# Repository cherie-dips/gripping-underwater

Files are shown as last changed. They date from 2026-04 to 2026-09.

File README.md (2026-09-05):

# Grippers for Underwater Manipulation

**Dipti Dhawade** · **Sai Chinmayi Kalapatapu** · **Tanu Adhikari** · **Uday Sodhi**  

**Mentor:** Prof. Sandeep Manjanna, Plaksha University

> 🏆 **3rd Place — SP Dutt Award For Innovation and Impact**

**🌐 Project website: https://cherie-dips.github.io/gripping-underwater/**

---

Underwater manipulation remains one of the most challenging unsolved problems in marine robotics. Gripping objects underwater is fundamentally harder than in open air, water creates drag that pushes objects away as fingers approach, surfaces become slippery, and buoyancy alters effective object weight. Most industrial grippers use rigid fingers that can crush fragile specimens such as corals and sponges. The ability of a robot to physically pick up, handle, or interact with objects underwater is critical for tasks like marine biology sampling, pipeline inspection, infrastructure repair, and environmental monitoring.

Our motivation comes from our AUV project, where we found our vehicle could navigate and detect objects but had no reliable way to interact with them physically. Through our literature review, we learned that underwater grippers must serve three core functions: detachment, collection, and storage. Each demands fundamentally different gripper behaviours [1]. Rigid parallel and claw grippers dominate current designs but offer poor force control and no tactile feedback. Soft grippers address some limitations but risk tearing under cyclic pressure.

Gathering these reflections, we set out to design a general-purpose underwater gripper; one capable of reliably grasping a range of object types, including but not limited to spherical, rigid, delicate and slippery objects. Our approach uses the fin-ray effect [2], a mechanism inspired by ray-finned fish bone structure, where flexible fingers passively conform around an object upon contact, distributing load rather than concentrating it. Starting from an open-source three-finger design, we iterated to a four-finger configuration, redesigned the worm-follower actuation base, modified internal finger structures, and relocated the pivot point to increase opening range. Prototypes were 3D-printed in TPU and ABS to make them lightweight, water-resistant, and cheaper.

However, trial and error revealed a clear trade-off: moving the pivot outward improved how wide the gripper could open, but the fingertips no longer met at the centre during closure. This left a gap that stopped the gripper from grasping small or thin objects. Two fixes were explored: adding a curve to the pivot region of the finger arm, and changing the slit angles in the worm-follower base. In parallel, we investigated a rack-and-pinion mechanism where a central gear drives all fingers at once,
completely removing the dependency on pivot placement. The rack-and-pinion prototyping introduced its own problems around lateral drift of the finger and structural fragility, which were resolved through revised clamp geometry and increased wall thickness. 

---

## Prototype Iterations

| Fig 1. 3-finger fin-ray gripper | Fig 2. Iterated 4-finger design | Fig 3. Iterated 4-finger rack-and-pinion |
|:-:|:-:|:-:|
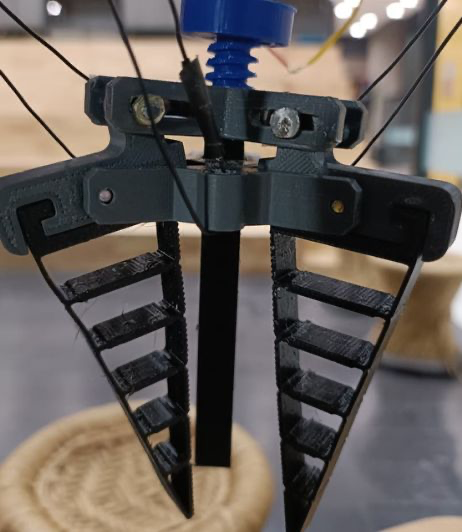
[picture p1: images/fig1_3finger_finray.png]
3-finger fin-ray gripper
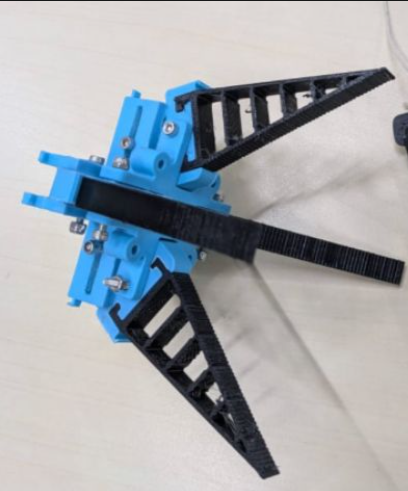
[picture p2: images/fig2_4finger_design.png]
Iterated 4-finger design
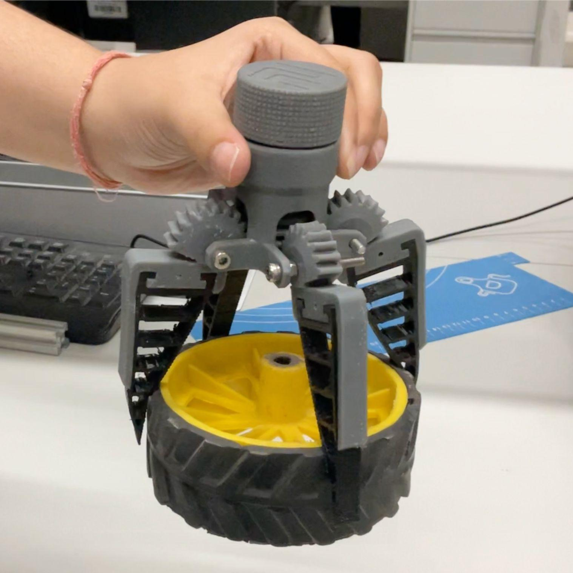
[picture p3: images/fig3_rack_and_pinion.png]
Iterated 4-finger rack-and-pinion
|  |  |  |
| *(Inspired by: "LAD Robotics")* | *(Inspired by: "Print Challenge")* | *(Inspired by: "Print Challenge")* |

---

## Next Steps

The next phase involves fabricating and comparing the fin-ray prototype against alternative mechanisms across defined test objects. Future work includes silicone moulding of finger surfaces for better grip on slippery objects and developing computer vision based grasping for robust object manipulation across different gripper types. Through our project, we aim to contribute towards expanding the current literature available on underwater grippers and the development of a more reliable, versatile, and damage-minimising gripper solution for critical marine manipulation tasks.

---

## References

[1] Mazzeo, A., Aguzzi, J., Calisti, M., Canese, S., Angiolillo, M., Allcock, A.L., Vecchi, F., Stefanni, S. and Controzzi, M., 2022. Marine robotics for deep-sea specimen collection: a taxonomy of underwater manipulative actions. *Sensors*, 22(4), p.1471.

[2] Sofla, M.S., Golshanian, H., Sklar, E.I. and Calisti, M., 2025. Modeling and modification of fin-ray effect grippers to improve their load capacity and grasp stability. *Sensors and Actuators A: Physical*, 392, p.116711.

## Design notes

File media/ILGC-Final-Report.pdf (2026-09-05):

# Autonomous Underwater Vehicle

## Grippers for Underwater Manipulation

Team Members
Dipti Dhawade (U20230146) dipti.dhawade.ug23@plaksha.edu.in Sai Chinmayi Kalapatapu (U20230085) chinmayi.k.ug23@plaksha.edu.in Tanu Adhikari (U20230115) tanu.adhikari.ug23@plaksha.ed.in Uday Sodhi (U20230020) uday.sodhi.ug23@plaksha.edu.in

Mentor: Prof. Sandeep Manjanna, Plaksha University

## Abstract

Underwater manipulation remains one of the most challenging unsolved problems in marine robotics. Existing industrial grippers are mostly rigid, which means they can crush delicate specimens like corals. Soft grippers are gentler but tend to tear under repeated pressure cycling at depth. Our AUV that we worked on earlier in ILGC could already navigate and detect objects, but had no reliable way to physically interact with them. Therefore, this project set out to design, prototype, and test a general-purpose underwater gripper capable of grasping a range of objects, including spherical, thin, slippery, and rigid ones.

We approached this by adopting the fin-ray effect, a mechanism inspired by the bone structure of ray-finned fish, where flexible fingers passively wrap around an object on contact instead of squeezing it from one direction. Starting from an open-source 3-finger design, we moved to a 4-finger configuration, redesigned the worm-follower actuation base, changed the internal structure of the finger arms, and moved the pivot point outward to increase the opening range. Parts were 3D printed in SLA, TPU and ABS.
However, trial and error revealed a clear trade-off: moving the pivot outward improved how wide the gripper could open, but the fingertips no longer met at the centre during closure. This left a gap that stopped the gripper from grasping small or thin objects. Two fixes were explored: adding a curve to the pivot region of the finger arm, and changing the slit angles in the worm-follower base. In parallel, we investigated a rack-and-pinion mechanism where a central gear drives all fingers at once, completely removing the dependency on pivot placement. The rack-and-pinion prototyping introduced its own problems around lateral drift of the finger and structural fragility, which were resolved through revised clamp geometry and increased wall thickness. The testing plan has been fully defined and will be executed before the end-semester presentation.
Future work includes silicone moulding of finger surfaces for better grip on slippery objects. This project lays the foundation for a capable, modular underwater gripper that can be handed over to the next cohort for completion and field testing.

## 1. Introduction

### 1.1 Motivation

In the previous semester of ILGC, our team worked on an Autonomous Underwater Vehicle capable of navigating underwater and identifying objects in its environment. While the vehicle could move toward and locate objects, it lacked a reliable way to physically interact with them. This gap between detection and manipulation was what motivated the gripper project. With a dependable gripper, the AUV could collect samples, retrieve objects, and perform meaningful tasks underwater rather than just observing them.

This problem turns out to be harder than it first appears. Gripping objects underwater is fundamentally different from gripping them in air. As a gripper's fingers approach an object, the surrounding water creates drag that pushes the object away before contact is even made. Once contact happens, wet surfaces are far more slippery, making it harder to maintain a secure hold. Buoyancy also changes the effective weight of the object, which affects how much force is needed to lift or move it. Together, these factors make underwater grasping significantly more challenging than the same task in air (Mazzeo et al., 2022a)

The gripper designs used in industrial underwater robotics today are mostly rigid, using parallel fingers or claw-style mechanisms. These work well for hard, robust objects but are poorly suited to anything fragile. Corals, sponges, and biological specimens can be crushed or damaged by the concentrated contact forces exerted by rigid fingers(Mazzeo et al., 2022b). Research has been moving toward softer gripper designs that wrap around an object more gently, distributing force over a larger contact area. Soft grippers are more tolerant of small positioning errors and less likely to damage delicate specimens. However, soft materials have lower mechanical strength and tend to tear under the repeated pressure changes that occur when a robot dives and resurfaces (Mazzeo et al., 2022a). Our goal was to find a design that sits between these two extremes, robust enough to function reliably but gentle enough to handle fragile objects without causing damage.

### 1.2 Problem Statement

The goal of this project was to design, prototype, and iteratively improve an underwater robotic gripper for the AUV. The gripper needed to reliably grasp a range of object types, including thin, circular, delicate, slippery, and rigid objects. It also needed to meet practical constraints: it had to be lightweight to avoid adding too much to the vehicle, water-resistant to survive the operating environment, and simple enough to be actuated by a single drive motor.

## 2. Literature Review

Given the physical challenges described above, designing an effective underwater gripper requires more than engineering intuition, it demands a systematic understanding of what such a gripper actually needs to do, what currently exists, and where existing solutions fall short. The following review builds that understanding in three steps: first, establishing what manipulation tasks and requirements define the problem space, then examining the landscape of existing gripper designs and their limitations, and finally reviewing the mechanical principles that inform a more capable approach.

### 2.1 Taxonomy of Underwater Manipulative Actions

Before evaluating any gripper design, it is necessary to understand what underwater manipulation actually involves at a task level. A foundational contribution here was made by Mazzeo et al. (2022a), who developed the first formal taxonomy of underwater manipulative actions for deep-sea specimen collection. Their methodology involved structured interviews with seventeen domain experts, marine biologists, ROV pilots, and geologists, supplemented by analysis of field video documentation. The study systematically categorised underwater manipulation into three primary task types: detachment, collection, and storage. Detachment actions ranged from non-retaining forms, such as pushing and scraping, to prehensile retaining forms, including grip-and-twist and cage-and-pull. The collection encompassed gripping, caging, suction, and tool-gripping. Storage included suction-based transfer, pouring, and object release. The taxonomy further organises these into four hierarchical levels: the full manipulation sequence, the atomic manipulation (a specific object interaction), the key-event (the period between contact creation and release), and the manipulation primitive (a basic robot command such as move or exert force). Manipulation goals are additionally classified into hand-only actions, separation actions, and release-determined actions. This decomposition is useful for mapping gripper requirements to specific task stages rather than treating manipulation as a single undifferentiated action.

Each task type maps to specific gripper contact configurations: point, edge, flat, hook, hollow, grasp, envelope, and suction flow. This framework provided a principled basis for evaluating whether any given gripper design is mechanically fit for the range of manipulation tasks encountered underwater.

The study also identified the primary failure modes of current underwater manipulators: squashing of soft specimens on full closure, poor force control dependent on pilot experience, slow closure speed that allows mobile organisms to escape, absence of force and tactile feedback, and impractical tool-change procedures in currents. These failure modes directly motivated the transition in this project from the prior cup-with-lid manipulator to a compliant, force-distributing gripper design.

Engineering requirements synthesised from this taxonomy span three dimensions:

1. Operational: grippers must be lightweight, energy-efficient, corrosion-resistant, and compatible with the arm's actuation and communication systems.
2. Environmental: they must be fully water and pressure-resistant, near-neutrally buoyant, and functional across ocean temperatures of 0°C to 3°C.
3. Task-related: requirements include high-resolution position and force control, reactive closure speed, and the capacity to handle objects ranging from sub-centimetre specimens up to 15 cm (Mazzeo et al., 2022a).

### 2.2 Existing Gripper Mechanisms and Trends

With a clear picture of what underwater grippers need to accomplish, the next question is whether existing designs meet those requirements. A companion systematic review by Mazzeo et al. (2022b) surveys the state of existing underwater grippers and organises them into four mechanical classes: parallel fingers, opposed or intermeshed fingers, grabber claws, and cage claws. Actuation is primarily hydraulic for deep-sea ROV-deployed systems, electric for laboratory and pool prototypes, and occasionally pneumatic. Associated storage systems include suction samplers, scoops, sediment corers, and Niskin bottles.

The review distinguishes prototype maturity by testing environment. Lab-tank prototypes typically combine rigid and soft technology with electric, hydraulic, or pneumatic actuation. Prototypes tested in pools or open sea conditions are predominantly purely rigid or purely soft with electric actuation. Grippers deployed on deep-sea ROVs tend toward fewer joints and actuators and are mainly hydraulically actuated. This gradient reveals a clear pattern: design complexity and softness decrease as deployment depth and operational demands increase, reflecting the current limits of soft robotic durability in high-pressure, real-world conditions.

The review identifies a consistent gap: research prototypes tend to lack robustness outside their designed scenarios, while operationally deployed marine grippers closely resemble rigid industrial designs offering limited adaptability to irregular specimen shapes. Tactile sensing remains an unsolved problem, with current workarounds relying on mechanical stiffness selection through spring-based compliance, adjusted transmission, or jamming structures, rather than direct contact feedback.

A significant documented trend is therefore a shift toward bio-inspired, soft gripper designs that address these gaps. Soft grippers offer tolerance to positioning errors and reduced risk of damage to fragile specimens. Their limitations include lower mechanical strength and susceptibility to tearing under cyclic pressurisation, a critical consideration for repeated operation. Ongoing mitigation strategies include fibre reinforcement, improved interfaces between soft and rigid components, and modular construction for simplified maintenance (Mazzeo et al., 2022b). This sets up the central design question for this project: what mechanical principles make a soft gripper both compliant and reliable?

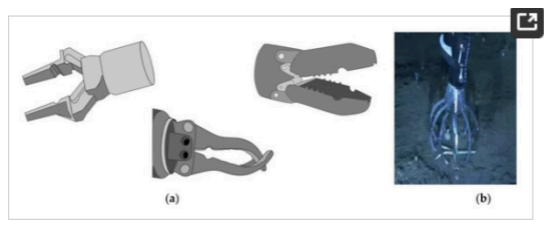
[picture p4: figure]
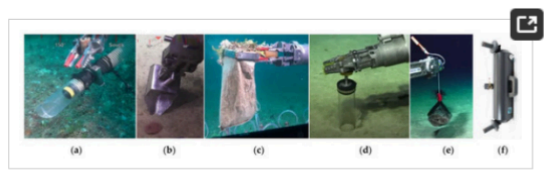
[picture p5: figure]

Fig1. Various types of Gripper and Collection tools highlighted in the paper

(Mazzeo, A., Aguzzi, J., Calisti, M., Canese, S., Vecchi, F., Stefanni, S., & Controzzi, M. (2022). Marine robotics for deep-sea specimen collection: A systematic review of underwater grippers. Sensors, 22(2), Article 648. https://doi.org/10.3390/s22020648)

### 2.3 Grasping Forces: Normal and Shear Mechanisms

Understanding why soft grippers perform better on fragile objects requires a closer look at the mechanics of grip itself. Hawkes et al. (2015) provide a useful framework, distinguishing between normal-force and shear-force grasping strategies. Normal-force approaches include wrapped or form-closure grasps, where the gripper geometrically surrounds the object and friction is not required, and squeeze or force-closure grasps, where inward clamping generates sufficient friction for a stable hold. Shear-force approaches instead exploit surface microstructure: gecko-inspired silicone ridges that activate Van der Waals adhesion forces when loaded laterally, increasing contact area without requiring compressive clamping.

This distinction is directly relevant for underwater design. The aquatic environment reduces surface friction on wet and smooth objects, making pure force-closure strategies unreliable. Form-closure, by contrast, does not depend on friction at all, making it inherently better suited to the underwater context. The fin-ray gripper pursued in this project primarily employs a form-closure strategy, where compliant fingers conform to the object's geometry and distribute load across a large contact area. The planned addition of silicone surface features draws on the Hawkes et al. (2015) finding that shear-based adhesion can supplement conformational wrapping in scenarios where geometric enclosure alone is insufficient.

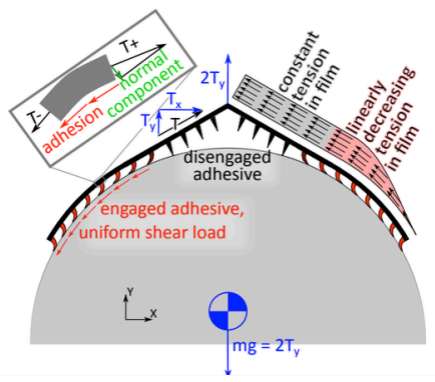
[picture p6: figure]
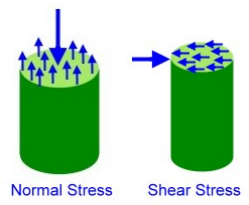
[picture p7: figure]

Fig2. Gripping using Shear Forces

(Hawkes, E.W., Christensen, D.L., Han, A.K., Jiang, H. and Cutkosky, M.R., 2015. Grasping without squeezing: Shear adhesion gripper with fibrillar thin film. In 2015 IEEE ICRA (pp. 2305-2312))

### 2.4 Fin-Ray Effect and Structural Compliance

Form-closure grasping requires fingers that can passively conform to an object's shape without active sensing or control. The Fin Ray Effect, derived from the mechanical behaviour of fish pectoral fins, provides exactly this. The geometry consists of two flexible outer beams connected by internal transverse ribs, forming a series of compliant triangular cells. When a lateral load is applied to the tip, rather than deflecting away from the force, the structure bends toward it. This counterintuitive response enables passive mechanical compliance: the finger conforms to an object's contour, increasing contact area while reducing localised pressure.

Srinivas et al. (2024) systematically investigated how different internal filling geometries affect the performance of 3D-printed fin-ray fingers, testing multiple rib and infill patterns against objects of varying shape and stiffness, including coffee cups and wooden blocks. Their key finding was that internal structure significantly influences the bending profile and grip strength of the finger, with different infill patterns suited to different object types. This provides the direct rationale for prototyping and comparing multiple internal finger geometries in this project, including the original transverse-rib design and a triangulated infill variant. The study also confirms TPU (thermoplastic polyurethane) as an appropriate finger material given its elastic memory, resistance to cyclic deformation, and printability (Srinivas et al., 2024).

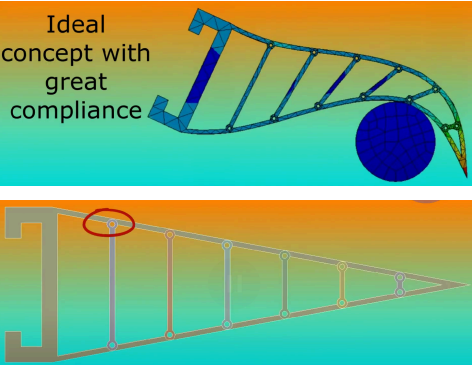
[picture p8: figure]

Fig. 3: Finray gripper deforming to envelop the object

(Image from RoboSub 2025 Technical Design Report Nanyang Technological University (NTU) )

Together, these studies form the foundation for the iterative design and prototyping approach described in the following sections.

## 3. Modelling & Analysis - Design Modifications

This section documents the full design evolution of the underwater gripper mechanism. We started with the worm-follower fin-ray gripper and then iterated it from a 3-finger to a 4-finger design. After encountering issues with the worm follower geometry, we then shifted to rack-and-pinion architecture, culminating in the decision to fabricate the final design in aluminium for structural durability.

### 3.1 Worm-Follower Fin-Ray Gripper

### 3.1.1 Design Concept and Initial Configuration

The first gripper mechanism designed for this project was based on a worm-follower actuation system combined with fin-ray fingers. In this mechanism, a motor-driven worm gear drives a follower that translates rotational motor output into the radial motion of the finger arms. All components were modelled in Fusion 360 and 3D printed in ABS and TPU. The initial printed assembly comprised a worm-follower base, a front base plate, fin-ray fingers (TPU material), and a motor-mount holder. The original design began as a 3-finger configuration, adapted from reference designs and modified in-house to suit the grasping requirements of the project.

3.1.2 3-Finger to 4-Finger Design Modification
The original 3-finger gripper (Fig. 4 (a)) was modified to a 4-finger(Fig. 4(b)) configuration as an iterative improvement. The rationale for this change was to test whether an additional finger arm would improve grasping stability, distribute grip force more evenly, and increase success rates when grasping larger, rounder, or asymmetric objects.

The following changes were made to the worm-follower base to support four fingers:

a. The base was redesigned to accommodate four equidistant arm channels instead of three.
b. The slit geometry was enlarged to allow greater freedom of movement for the rivets acting as pivot fasteners.
c. Hooks were added to the base to pull the finger arms upright after each grasping cycle, ensuring consistent return to the open position.

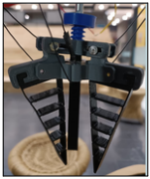
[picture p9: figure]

Fig. 4 (a) 3-finger configuration | Fig. 4 (b) 4-finger configuration

### 3.1.3 Pivot Relocation and the Closure Trade-Off

To improve the opening range of the gripper, enabling it to grasp larger and rounder objects, the pivot location of the finger arms was shifted outward(Fig. 5). This modification confirmed improved range of motion.

However, upon actuation, a significant and unexpected problem emerged: the fingers were not closing fully. Moving the pivot outward shifted the effective closing axis of each finger arm, meaning the fingertips no longer converged at the centre during closure. The result was a persistent gap at the fingertips that limited the gripper's ability to grasp small and thin objects, a direct trade-off with the improved opening range.

Two corrective approaches were evaluated to restore full closure while retaining the wider opening range:

a. Adding a curve to the pivot region of the finger arm to redirect the closing trajectory back toward the centre, compensating geometrically for the axis shift.
b. Modifying the slit angles in the worm-follower base to alter the rivet travel path and correct the closing axis without changing the finger arms themselves.
Neither approach fully resolved the trade-off. The geometric constraints of the worm-follower mechanism meant that pivot location, opening range, and closure geometry were inherently coupled and improving one parameter degraded another. This limitation made us explore an alternative actuation mechanism that could decouple these constraints entirely

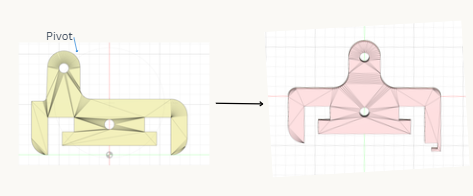
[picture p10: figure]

Fig. 5: Change in pivot point of Clamp

### 3.2 Transition to the Rack-and-Pinion Design

### 3.2.1 Rationale for the Mechanism Change

The rack-and-pinion gripper(Fig. 6) was selected as the replacement architecture after a systematic analysis of the worm-follower's structural limitations. The rack-and-pinion mechanism resolves this at the kinematic level:

- A central pinion gear, driven by the motor, meshes directly with rack teeth cut into the base of each finger.
- As the pinion rotates, all fingers are driven simultaneously and symmetrically - inward to close, outward to open.

- Both full closure and maximum opening are governed purely by rack travel length and pinion rotation, completely independent of any pivot geometry.
This architecture is also compact, straightforward to model in Fusion 360, and ensures perfect synchrony across all four fingers without additional linkage or geometry changes. We adapted an existing open-source 3-finger rack-and-pinion design (PrintChallenge) and re-engineered it for a four-finger.

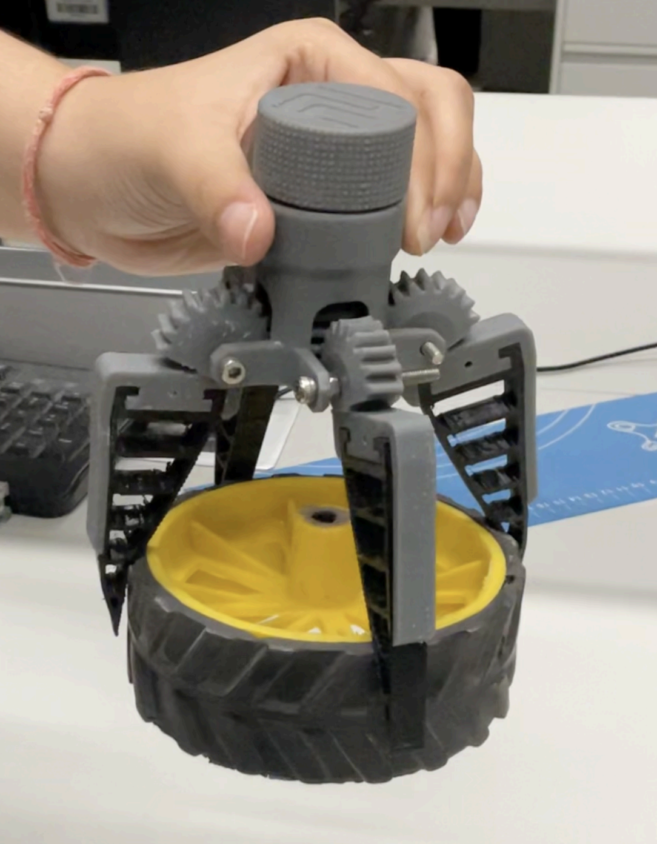
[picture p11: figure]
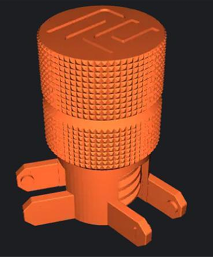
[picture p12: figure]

Fig. 6: Rack and pinion design

### 3.2.2 Rack-and-Pinion Design Iterations

Following the mechanism transition, the rack-and-pinion gripper underwent four distinct design iterations. Each iteration was driven by a specific failure observed during physical prototyping.

Iteration 1 - Initial Clamp: Lateral Drift Failure

Upon assembling and actuating the initial clamp design, the finger arms were found to deflect tangentially, sliding sideways perpendicular to their intended radial axis of motion. This lateral drift caused misalignment during closure, preventing a clean and symmetric grip.

Root cause: No lateral constraint geometry in the clamp channels; the finger arms had freedom to move tangentially as well as radially.

Corrective action: The clamp was redesigned to incorporate lateral guide walls that confine each finger arm strictly to its radial axis, eliminating tangential drift.

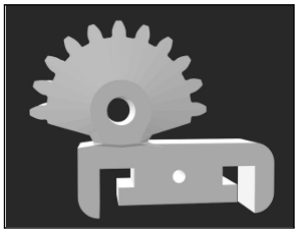
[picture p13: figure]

Fig 7(a): Original clamp for Rack and pinion. | Fig. 7(b): Clamp with support for Rack and pinion

Iteration 2 - Pin-and-Ray Mechanism: Structural Failures
During printing and assembly of the pin-and-ray mechanism, two structural failures were observed:
a. Base fracture: The bottom section was thin, causing it to fracture under assembly loads.
b. Side wall breakage: The walls between the two finger clamp holders lacked bridging support and were separating under actuation.
Corrective actions: Base thickness was increased. Reinforcing support geometry was added between the clamp holders to prevent separation.

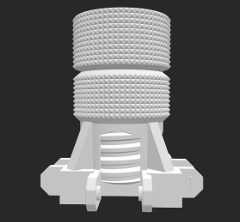
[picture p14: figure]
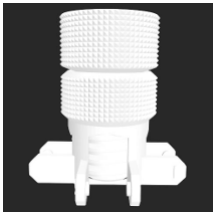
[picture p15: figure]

Fig8(a): Original Rack and Pinion | Fig8(b): Redesigned Rack and pinion

Iteration 3 - SLA Print Constraint: Splitting the Assembly
After finalising the revised geometry, a manufacturing constraint was identified: the screw-and-clamp-holder assembly could not be printed as a single part on the SLA printer. SLA printing was required because ABS was weak and produced an insufficient surface finish on the screw interface. Rough surfaces introduced excessive friction, degrading the mechanism's performance. SLA's finer resolution and smoother surfaces were necessary for the tight-tolerance screw travel.

Solution: The assembly was split into two separately printable parts:

1. the screw section and
2. the clamp holder section

to be joined post-print.

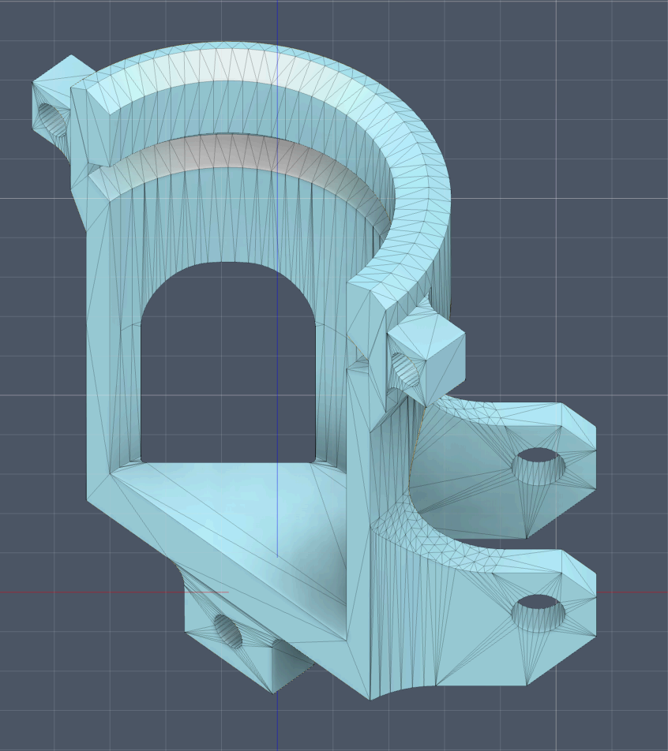
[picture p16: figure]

Fig. 9 Split Clamp Holder

Iteration 4 - SLA Material Failure: Transition to Aluminium
Despite resolving the print geometry, SLA-printed parts fractured under operational loads. When mechanical pressure was applied during screw actuation, the structure cracked. Repeated loading cycles during grasping exceeded the fatigue tolerance of the material.

Solution: We decided to fabricate the rack-and-pinion body in aluminium. Aluminium provides the surface finish quality required for smooth screw motion while delivering the structural strength and fatigue resistance that neither ABS nor SLA printing could offer simultaneously. The aluminium build is currently underway.

### 3.3 Fin-Ray Finger Internal Fill Geometry Variations

A key design modification carried out in parallel with the actuation mechanism work was the modification of the internal fill geometry of the fin-ray fingers. The standard fin-ray finger relies on its internal lattice structure to provide passive compliance, i.e., the finger deflects and wraps around an object on contact. The specific geometry of that internal structure directly governs the stiffness, compliance, and contact behaviour of the finger, making it a critical design variable for grasping different object types.

We designed and printed two distinct internal fill variants to evaluate how geometry affects grasping suitability:

Variant 1 - Diagonal Cross-Braced Fill
The first variant features a diagonal cross-braced internal structure(Fig. 9). The fill consists of angled struts forming irregular triangular and trapezoidal cells that run diagonally across the width of the finger. This geometry creates stiffer, more directionally rigid fingers. The diagonal bracing resists deformation along the loading axis more effectively than orthogonal patterns.

The diagonal cross-bracing also results in a sharper, more pointed contact profile at the finger tip, making it well-suited to grasping square-edged and sharp-cornered objects. The strut geometry allows the finger to lock around angular features rather than slipping off curved or smooth surfaces.

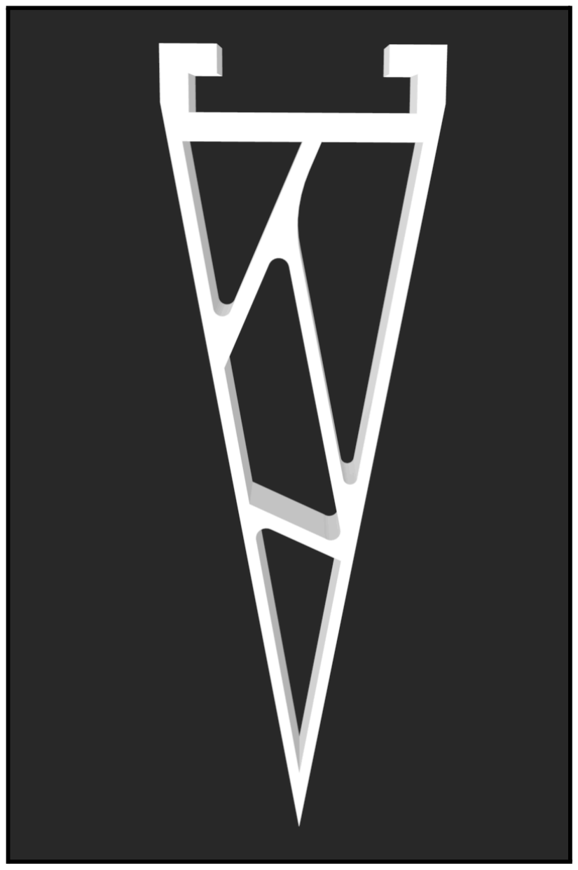
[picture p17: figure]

Fig 9: Diagonal Cross-Braced Fill

Variant 2 - Horizontal Ladder Fill with Microwedges
The second variant uses a horizontal ladder-style internal fill - a series of evenly spaced transverse ribs spanning the full width of the finger, creating uniform rectangular cells along the length of the finger(Fig. 10(a)). The outer edges of this variant also incorporate a microwedge profile along one side of the finger body to increase friction and grip strength on contact surfaces underwater.

The ladder fill distributes compliance more evenly along the length of the finger, allowing the finger to flex gradually and conform to curved or irregular surfaces. The uniform rib spacing ensures consistent stiffness across the finger length without concentrating stress at any single point. The microwedges serve a dual purpose: they increase the surface area in contact with an object and introduce mechanical interlocking features that improve grip friction on smooth, rounded, or slippery surfaces.

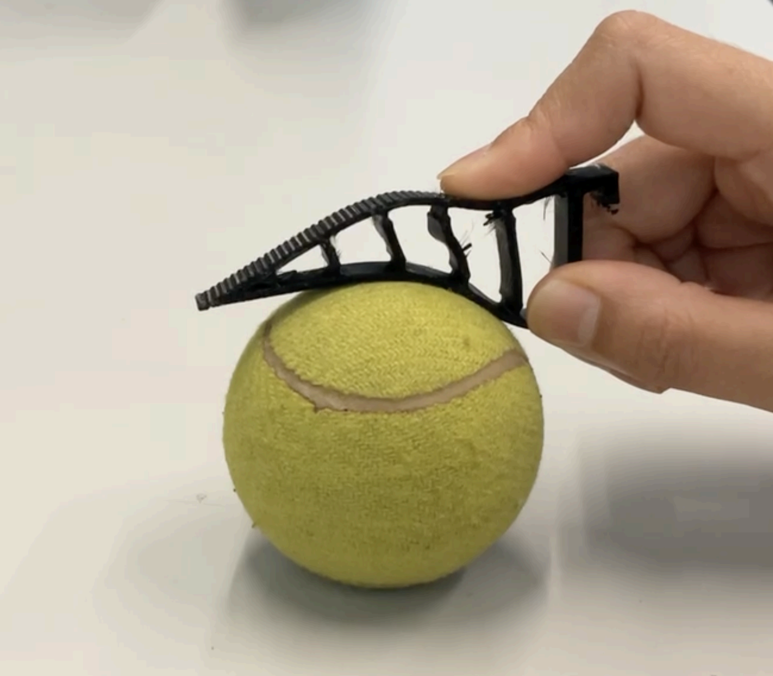
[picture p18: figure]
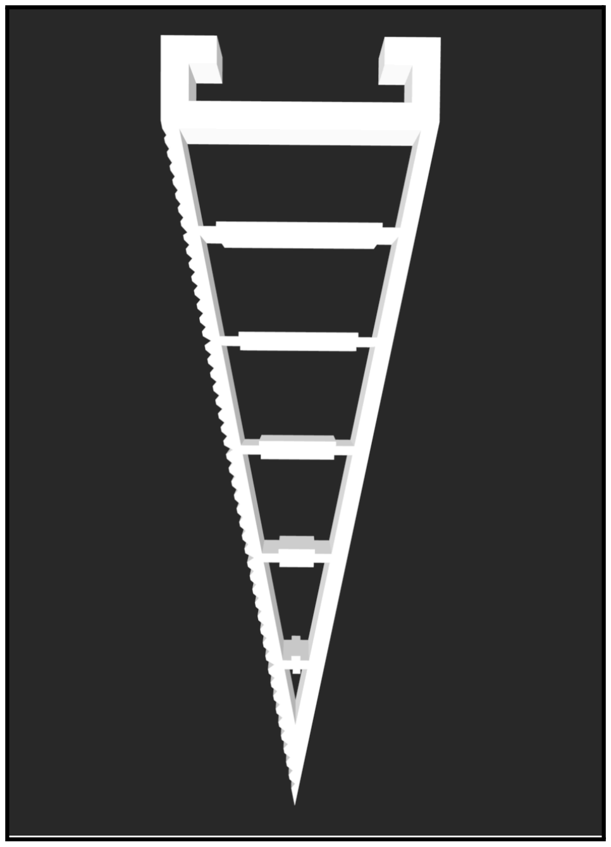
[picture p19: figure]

Fig10(a): Horizontal Ladder Fill with Microwedges | Fig10(b): Finger conforming around the ball

### 3.4 Outcomes, Results, and Decision-Making

### 3.4.1 What Worked

1. 3-to-4 finger expansion: The additional finger improved grasping stability and distributed grip force more evenly across object surfaces.
2. Rack-and-pinion kinematics: Fully resolved the opening-range vs. closure trade-off by decoupling both parameters from pivot geometry.
3. Lateral guide walls: Eliminated tangential finger drift, restoring clean and symmetric actuation.
4. Structural reinforcements: Increased base thickness and side-wall support successfully resolved the fracture and separation failures in the pin-and-ray mechanism.
5. Part-splitting for SLA: Dividing the assembly into two printable sections accommodated the SLA geometric constraint without requiring a complete redesign.
6. Spike structures and internal fill geometry modifications: Spike structures improved grip friction on slippery surfaces.

### 3.4.2 What Did Not Work

1. Worm-follower pivot relocation: While it improved opening range, it introduced an irresolvable fingertip closure gap - the two objectives were geometrically coupled.
2. Curved-pivot and slit-angle corrections: Neither compensating approach fully restored closure without sacrificing opening range; the coupling was inherent to the mechanism.
3. ABS printing for the screw mechanism: Print was fragile and insufficient surface finish introduced excessive friction in the screw interface.

4. SLA as sole manufacturing solution: SLA lacked the structural durability to withstand repeated screw actuation pressure, resulting in fracture under operational loads.

### 3.4.3 Decision-Making Process

All design decisions were grounded in direct physical evidence from prototype tests rather than theoretical prediction. The key decision points were:

1. Worm-follower → Rack-and-Pinion: Taken after confirming that neither the curved-pivot nor the slit-angle approach could resolve the closure gap within the worm-follower architecture. The rack-and-pinion was selected because it eliminates the coupling at the kinematic level.
2. ABS → SLA: Driven by observed surface finish inadequacy in FDM prints causing friction in the screw mechanism.
3. Part-splitting: Chosen as the minimum-change fix to the SLA print constraint, preserving all finalised geometry.
4. SLA → Aluminium: Taken after confirming SLA fracture under screw actuation loads. Aluminium was identified as the only available material that simultaneously meets the surface finish and strength requirements.

## 4. Testing

To test our various gripper designs, we referred to the performance metrics derived for robotic arms and grippers by the National Institute of Standards and Technology. (https://d1wqtxts1xzle7.cloudfront.net/66740293/nist.sp-libre.pdf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)
For the evaluation against all of the metrics defined, a split cylinder is used. A split cylinder is a standardised testing equipment used for robotic grippers. It consists of two three-dimensional (3D) printed structures that can hold two or more single-axis force load cells (sensors) (Falco et al., 2020).

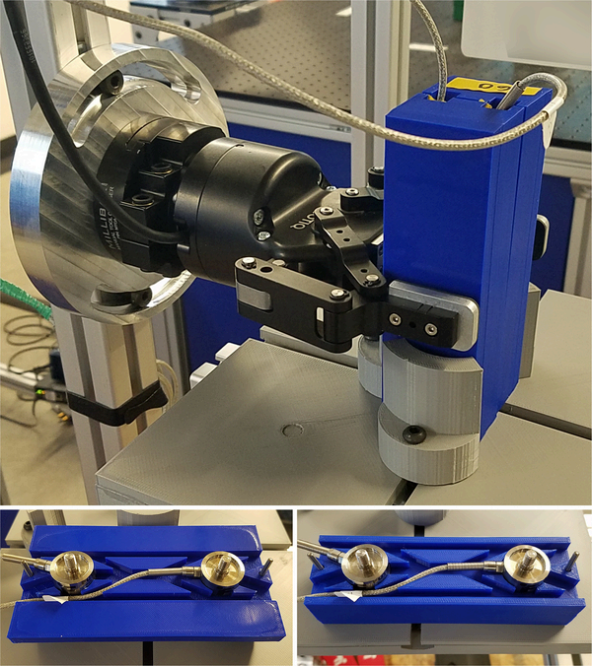
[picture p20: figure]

Fig 11: block split cylinder

Falco, J., Hemphill, D., Kimble, K., Messina, E., Norton, A., Ropelato, R., & Yanco, H. (2020). Benchmarking Protocols for Evaluating Grasp Strength, Grasp Cycle Time, Finger Strength, and Finger Repeatability of Robot End-effectors. IEEE Robotics and Automation Letters, 5(2). This author manuscript was made available in PubMed Central (PMC) on November 17, 2020

To measure the force exerted on the artifact, the load cells are oriented parallel to one another by the end-effector along the measurement axis (Falco et al., 2020). The design of the split cylinder is determined by the type of grasp. A block design is used for a pinch grasp, while the cylindrical design is used for wrap grasps (Falco et al., 2020). Due to our grippers exerting a wrap grasp, as detailed earlier in our literature review, we adapted the split cylinder to a cylinder design with a slot for the REES52 1kg wide bar Load Cell, as shown in Figure 12.

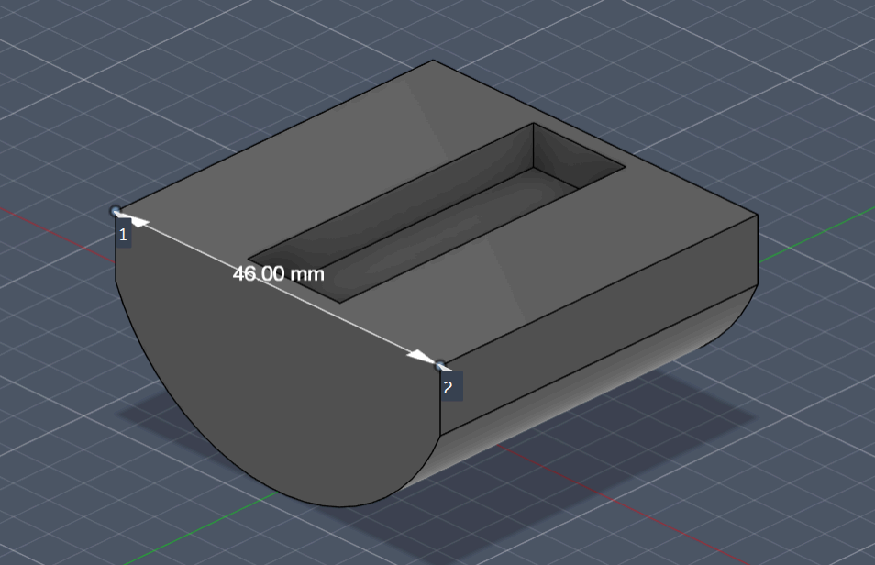
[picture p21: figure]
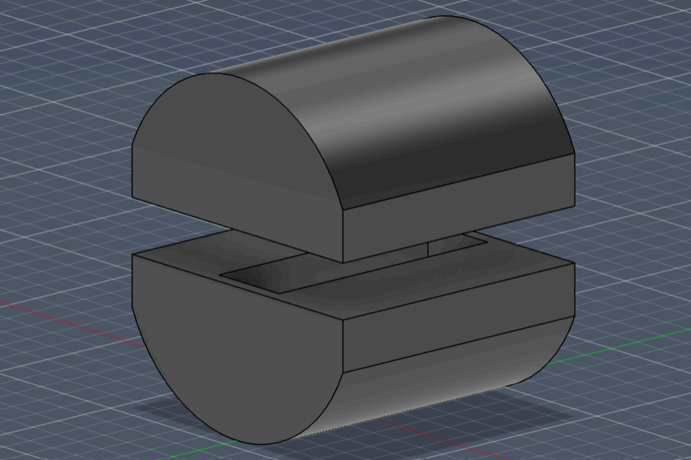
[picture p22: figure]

Fig 12: Our design of the split cylinder.

The results of the testing of all of our grippers will be presented in the end-of-semester presentation.

### 4.1 Testing Metrics

From the documentation by the National Institute of Standards and Technology, the metrics that are relevant and implementable for our project are grasp strength, slip resistance, and grasp cycle time. In this section, we focus on how we plan to proceed with the testing for these metrics.

### 4.1.1 Grasp strength:

Grasp Strength evaluates the maximum force a robotic hand can impose on an object, providing insight into payload capabilities. In order to evaluate it, a split cylinder is necessary.

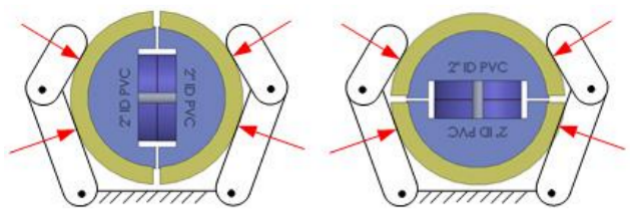
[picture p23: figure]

Fig 13: 13a: A diagrammatic representation of a split cylinder artifact in the 0° (left) and 90° (right) orientation, 13b: 3D printed 80mm and 50mm diameter prototypes of a split cylinder

(Falco, J., Van Wyk, K., & Messina, E. (2018). Performance metrics and test methods for robotic hands (DRAFT NIST Special Publication 1227). National Institute of Standards and Technology)

In this test, the gripper holds the maximum force it can exert for 5 seconds, then retracts to open fully. Repeat this process for 32 cycles for variously sized/oriented objects/artifacts. Additionally, ensure to ignore the first and last 10% of readings in 5 sec hold in order to not include quasistatic forces (Falco, Van Wyk, & Messina, 2018).

For each set of instantaneous force readings, we need to add forces across all load cells since they are in-line to yield a total grasp force Ftotal. This can be represented as:

Because forces are distributed from multiple angles, this test is run twice in two different orientations: 0° (where the internal load cell axis is parallel to the hand's palm) and 90° (where the load cell axis is perpendicular to the palm) (Falco, Van Wyk, & Messina, 2018)

### 4.1.2 Slip resistance

Slip resistance tests a hand's ability to resist slipping by measuring the maximum pull force it can withstand under a full-force wrap grasp. In order to rest this, a cylindrical artifact is grasped at maximum power, and a controlled, increasing axial force is applied to the object until "gross slipping" is visually confirmed. The maximum pull force is taken note of. (Falco, Van Wyk, & Messina, 2018)

Materials required for this test are: Standard ASTM D2665 PVC pipe segments (or split cylinder artifacts), a single-axis load cell, a mechanism for applying a controlled increasing axial pull force (e.g., a linear drive coupled with a cable and in-line spring), and data acquisition systems (Falco, Van Wyk, & Messina, 2018)

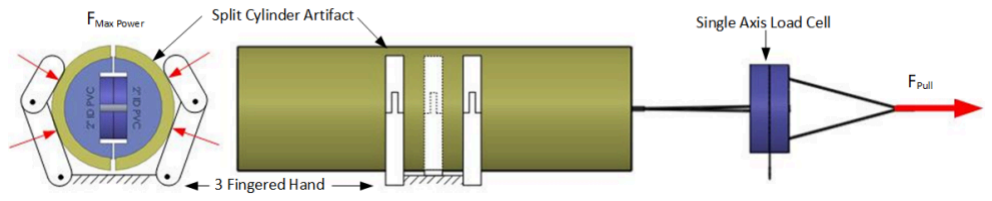
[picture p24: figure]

Fig: 14 A diagrammatic depiction of a three-finger wrap grasp on a cylindrical artifact under maximum power FMaxPower with the cylinder subjected to an axial pull force Fpull

(Falco, J., Van Wyk, K., & Messina, E. (2018). Performance metrics and test methods for robotic hands (DRAFT NIST Special Publication 1227). National Institute of Standards and Technology)

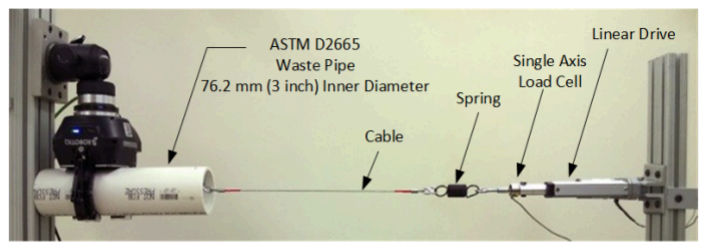
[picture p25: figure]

Fig 15 Prototype depicting slip resistance testing

(Falco, J., Van Wyk, K., & Messina, E. (2018). Performance metrics and test methods for robotic hands (DRAFT NIST Special Publication 1227). National Institute of Standards and Technology)

### 4.1.3 Grasp Cycle Time

The grasp cycle time measures the minimum time required for the gripper to achieve full closure from a “pre-grasp position” and return to the same position. For each test cycle, we record the pull force,

Fpull, over time. From this force/time plot, we extract the maximum pull force Fpull max. This experiment is run on various pipe sizes, from which we calculate the mean and 95% confidence intervals for various diameter sizes. (Falco, Van Wyk, & Messina, 2018)

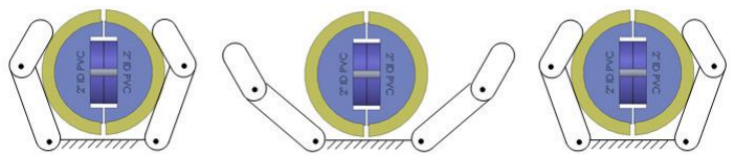
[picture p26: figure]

Fig 16 A diagrammatic representation of the split cylinder artifact in the dominant orientation relative to power grasp stages

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

The materials needed for this test are a single-axis load cell for 1D force and a split cylinder artifact. As done in the grasp strength section, for each set of instantaneous force readings, add forces across all load cells to calculate force Ftotal. (Falco, Van Wyk, & Messina, 2018)

### 4.2 Objects to test

In order to carry out the tests, we will be using objects of various sizes, textures and shapes. A set of objects that we will be testing on includes a tennis ball, nails (small, medium, large), marbles, a wooden box, a foam brick, a Rubik’s cube, a Pringles can and a mug, all of which can be found in the Yale-CMU-Berkeley Object Set. This is a widely established set providing physical objects and digital models for benchmarking. We will compare our results with submissions from similar grippers published (YCB Benchmarks, n.d.) Along with these objects, we will be testing on a wooden branch with algae to simulate slippery surfaces present underwater.

## 5. Conclusion

This project set out to design, prototype, and iteratively improve an underwater robotic gripper for an AUV capable of grasping a range of object types within the practical constraints of weight, water resistance, and single-motor actuation.

The fin-ray effect was selected as the core grasping principle because its passive mechanical compliance distributes contact force across a large area rather than concentrating it at a point, making it fundamentally better suited to fragile and irregular underwater specimens than rigid parallel-finger designs. This choice was validated by the literature and confirmed through physical testing: the TPU fin-ray fingers demonstrably conformed around curved objects, and the microwedge surface features on the ladder-fill variant improved grip friction on slippery surfaces, directly addressing the primary failure mode of underwater grasps identified by Mazzeo et al. (2022).

With regards to the design of the gripper, through our iterations, we initially explored a worm-follower architecture but ended up transitioning to a rack-and-pinion mechanism. This was due to the geometric coupling between the opening range and closure geometry in the worm-follower that could not be resolved through corrective modifications alone. Our transition to a rack-and-pinion mechanism eliminated this coupling at the kinematic level and delivered a robust design capable of simultaneous full closure and maximum opening range across all four fingers without dependency on pivot placement. Material selection was another aspect that proved equally critical and non-obvious. ABS failed at surface finish, and SLA failed at structural fatigue, causing us to finalise on a rack-and-pinion body in aluminium.

Our testing is currently underway as we plan on testing against three NIST SP 1227 metrics, grasp strength, slip resistance, and grasp cycle time, using a split cylinder artifact housing a REES52 1kg wide-bar load cell and interfaced with an HX711 amplifier.

Through the entire process of researching, prototyping, redesigning and testing, a significant outcome was not any single design decision, but the understanding of how engineering actually works. The circularity in this process of researching, prototyping, hitting a wall, stepping back, and redesigning from a new angle only to repeat it once again is not something that can be shortcut. Experiencing it firsthand across every layer of this project, from finger geometry to actuation mechanism to material selection to test infrastructure, is the most transferable thing this work produced.

Our work with the gripper is not yet complete. Post-testing, the primary direction that we see for future work is the adaptation of silicone projections onto the finger to further improve grip on the wet, smooth, and biologically irregular surfaces characteristic of the underwater operating environment. While this might not fall under the jurisdiction of ILGC-VI, we are hopeful that this direction and many others will be explored.

## References:

Hawkes, E.W., Christensen, D.L., Han, A.K., Jiang, H. and Cutkosky, M.R., 2015. Grasping without squeezing: Shear adhesion gripper with fibrillar thin film. In 2015 IEEE International Conference on Robotics and Automation (ICRA) (pp. 2305–2312). IEEE.

Mazzeo, A., Aguzzi, J., Calisti, M., Canese, S., Angiolillo, M., Allcock, A.L., Vecchi, F., Stefanni, S. and Controzzi, M., 2022a. Marine robotics for deep-sea specimen collection: a taxonomy of underwater manipulative actions. Sensors, 22(4), 1471.

Mazzeo, A., Aguzzi, J., Calisti, M., Canese, S., Vecchi, F., Stefanni, S. and Controzzi, M., 2022b. Marine robotics for deep-sea specimen collection: a systematic review of underwater grippers. Sensors, 22(2), Article 648.

Srinivas, G.L., Javed, A. and Faller, L.M., 2024. Versatile 3D-printed fin-ray effect soft robotic fingers: lightweight optimization and performance analysis. Journal of the Brazilian Society of Mechanical Sciences and Engineering, 46(6), p.382.

Falco, J., Van Wyk, K., & Messina, E. (October 2018). Performance Metrics and Test Methods for Robotic Hands (DRAFT NIST Special Publication 1227). National Institute of Standards and Technology, U.S. Department of Commerce

Falco, J., Hemphill, D., Kimble, K., Messina, E., Norton, A., Ropelato, R., & Yanco, H. (2020). Benchmarking Protocols for Evaluating Grasp Strength, Grasp Cycle Time, Finger Strength, and

Finger Repeatability of Robot End-effectors. IEEE Robotics and Automation Letters, 5(2). This author manuscript was made available in PubMed Central (PMC) on November 17, 2020.

CB Benchmarks. (n.d.). Results & records. YCB Benchmarks – Object and Model Set. https://www.ycbbenchmarks.com/world-records/

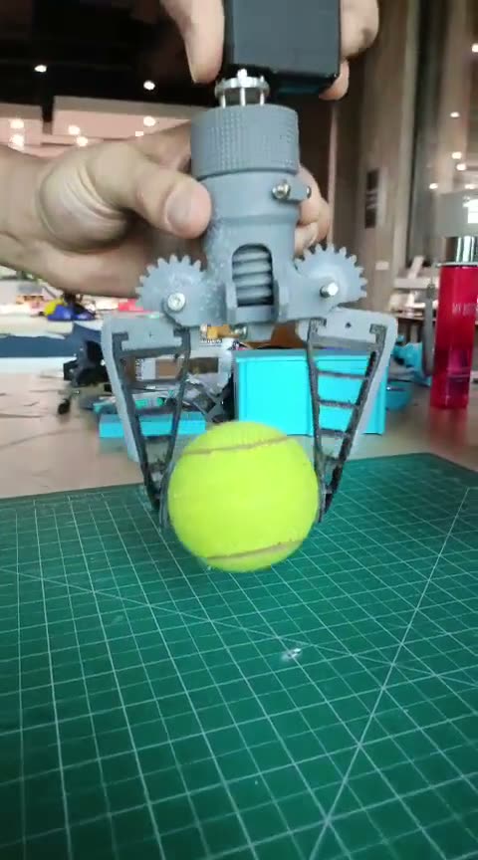
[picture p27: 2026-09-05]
media/hero_tennisball.jpg

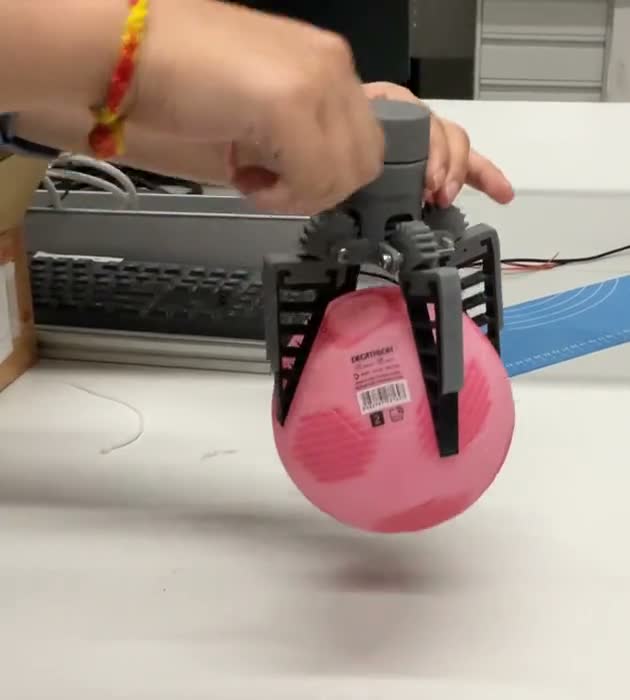
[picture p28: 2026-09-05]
media/grid/pinkball.jpg

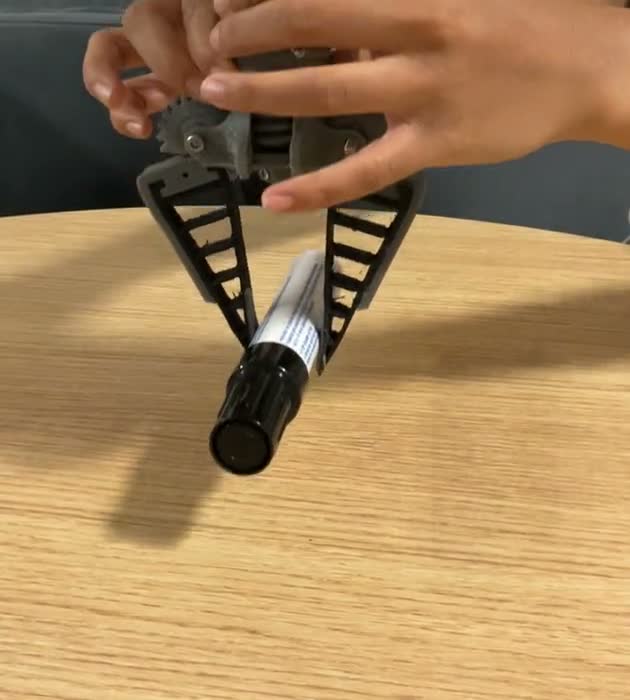
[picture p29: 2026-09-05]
media/grid/marker.jpg

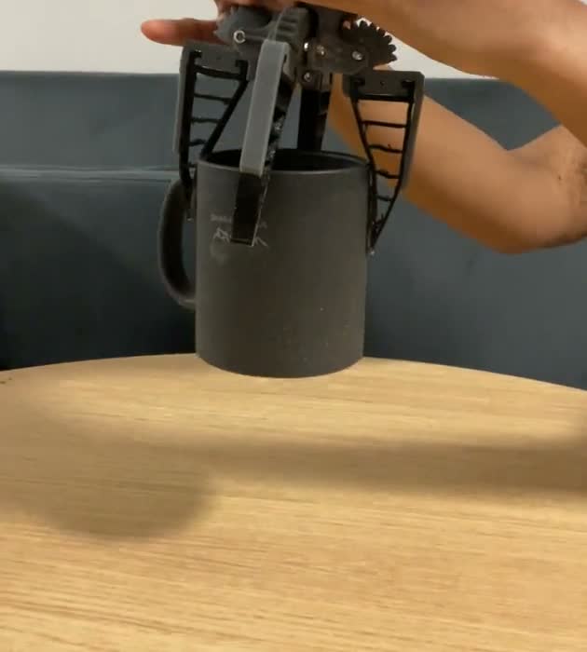
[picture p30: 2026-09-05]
media/grid/mug.jpg

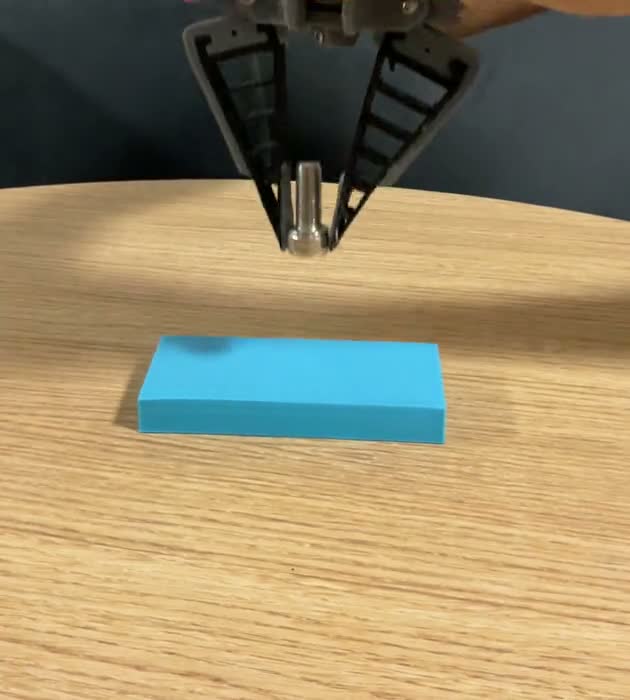
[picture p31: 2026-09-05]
media/grid/screw.jpg

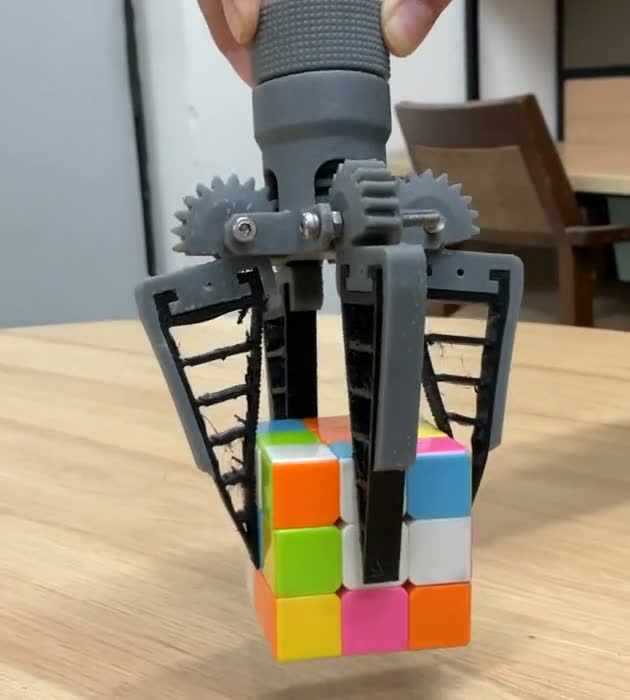
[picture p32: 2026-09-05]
media/grid/rubik.jpg

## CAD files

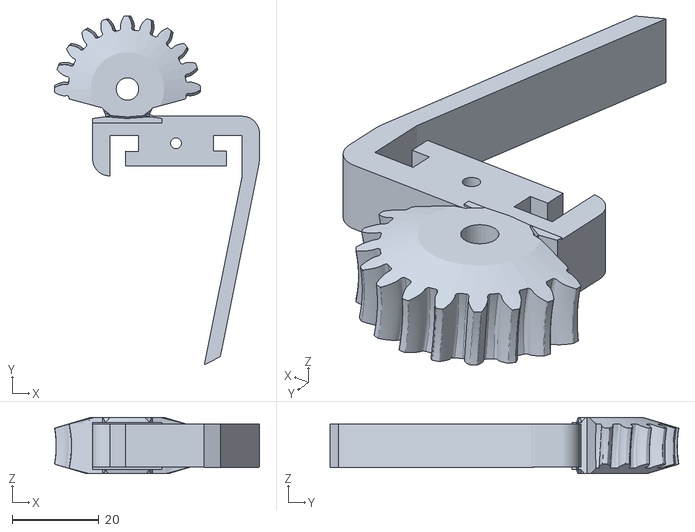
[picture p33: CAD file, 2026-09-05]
stl/Correct.stl
47.4 x 80.7 x 13.0

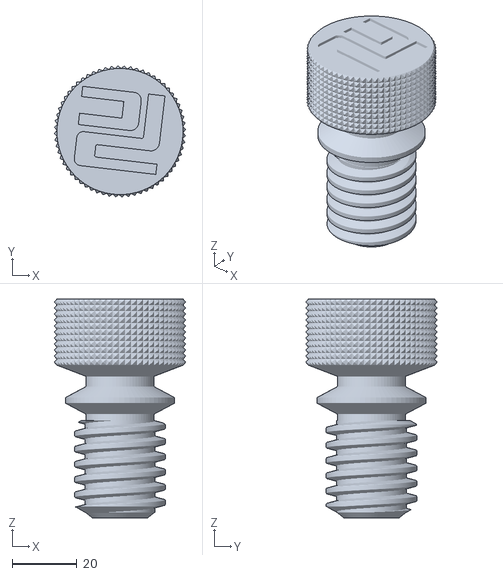
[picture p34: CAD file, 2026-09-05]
stl/Srew.stl
40.6 x 40.6 x 67.7

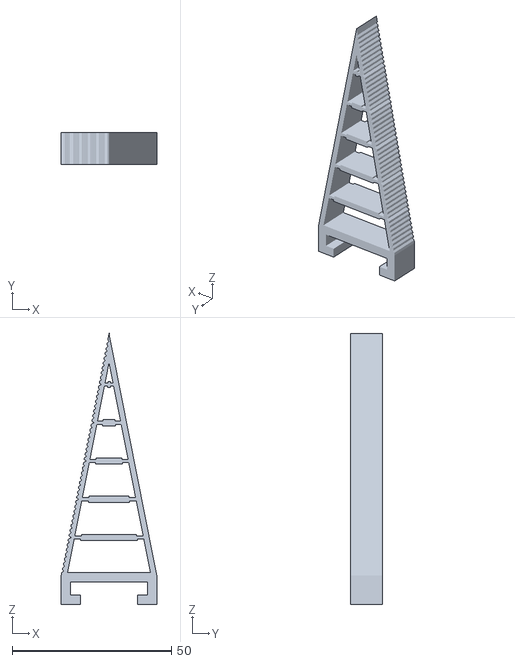
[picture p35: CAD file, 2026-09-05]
stl/Fixed_Correct_Finger.stl
30.0 x 10.0 x 85.0

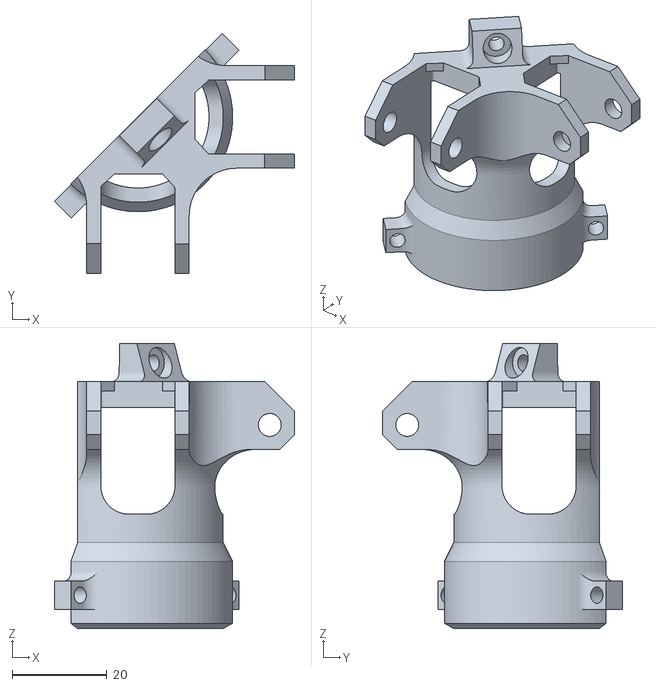
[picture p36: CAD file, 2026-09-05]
stl/final_body_screws.stl
50.6 x 50.6 x 60.1

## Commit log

2026-09-05 Add project website
    A single-page site at the repo root, styled after the Nerfies academic
    project-page template:
    - Title, team, mentor and award, with links to the slides, the YouTube
    video, the code and the final report
    - Abstract carried over from the README
    - The slide-39 tennis-ball clip as a silent looping showcase
    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
    [Correct.stl, Fixed_Correct_Finger.stl, Srew.stl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]
2026-09-05 Fix link preview image
    og:image was a relative path, which link scrapers do not resolve against
    the page URL, so shares fell back to whatever else they found. Point it
    at an absolute URL instead, and add og:url, the image dimensions, alt
    text and the Twitter card tags.
    The image is now a 1200x630 card built from the hero tennis-ball frame:
    the gripper wrapped around the ball, sharp and centred, over a blurred
    copy of the same scene.
    Claude-Session: https://claude.ai/code/session_017m5tHM7ZcPE1L1tUdmxj2P
2026-09-08 Restructure the header and tighten the page rhythm
    - Fold the subtitle into the title after a colon, all at one light
    weight, and give every run of text a shared 760px measure. Media (the
    grasp grid, the 3D cards, the showcase video) still spans the full
    940px container.
    - Move the award above the contributor names, drop the gold pill, keep
    the trophy, and set it uppercase and tracked out.
    - Drop the closing ILGC/Plaksha line, giving the last section a little
    more bottom padding so the page does not end abruptly.
    - Cut the space between sections from 46px to 18px.
    Claude-Session: https://claude.ai/code/session_017m5tHM7ZcPE1L1t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
2026-09-08 Widen the layout
    Container 940px to 1180px and the text measure 760px to 880px, so the
    text stays narrower than the media rather than filling the full width.
    The showcase video and the 3D viewer stages grow with it, otherwise the
    wider cards would leave the models sitting in short, letterboxed panels.
    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
2026-09-08 Reduce the main heading size
    2.65rem to 2.05rem at the top of the clamp. Line height opens slightly
    and the negative tracking eases off, both of which were tuned for the
    larger display size and read tight at this one.
    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
